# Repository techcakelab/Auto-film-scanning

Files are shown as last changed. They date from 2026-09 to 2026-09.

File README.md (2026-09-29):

# DIY Auto 35mm Film Scanner (ESP32 Autocarrier)


An open-source ESP32-based automatic film transport system for digitizing 35mm film using a digital camera. This project provides precise, high-speed frame-by-frame advancement with a custom **Hand Control Panel**.

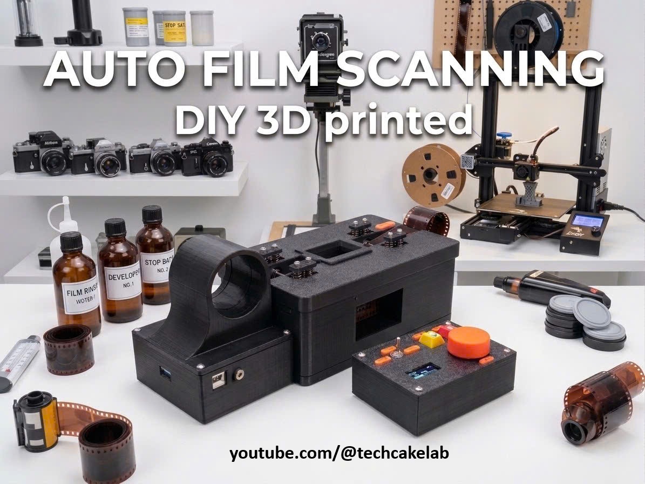
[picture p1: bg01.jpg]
Overall

---
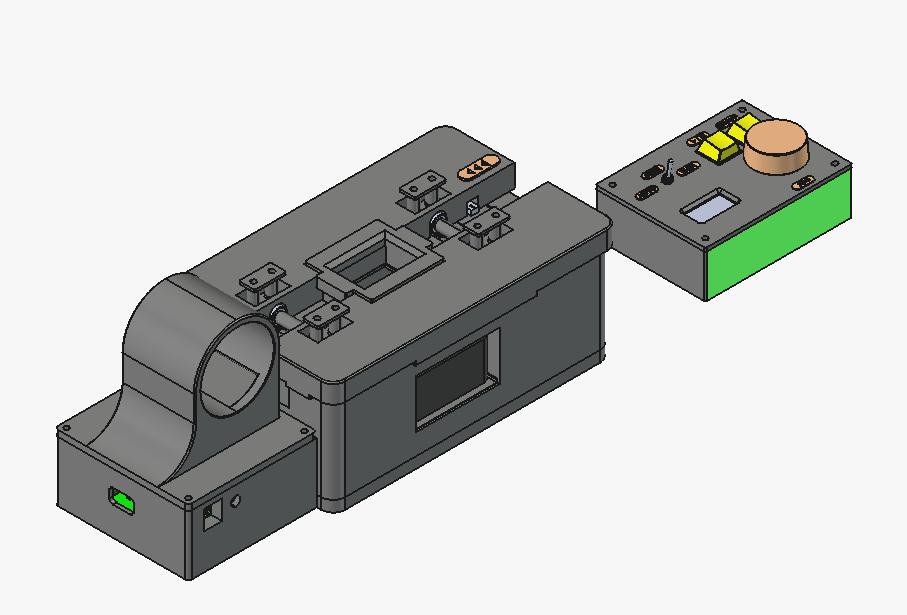
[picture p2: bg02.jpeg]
WithHandHeld

---
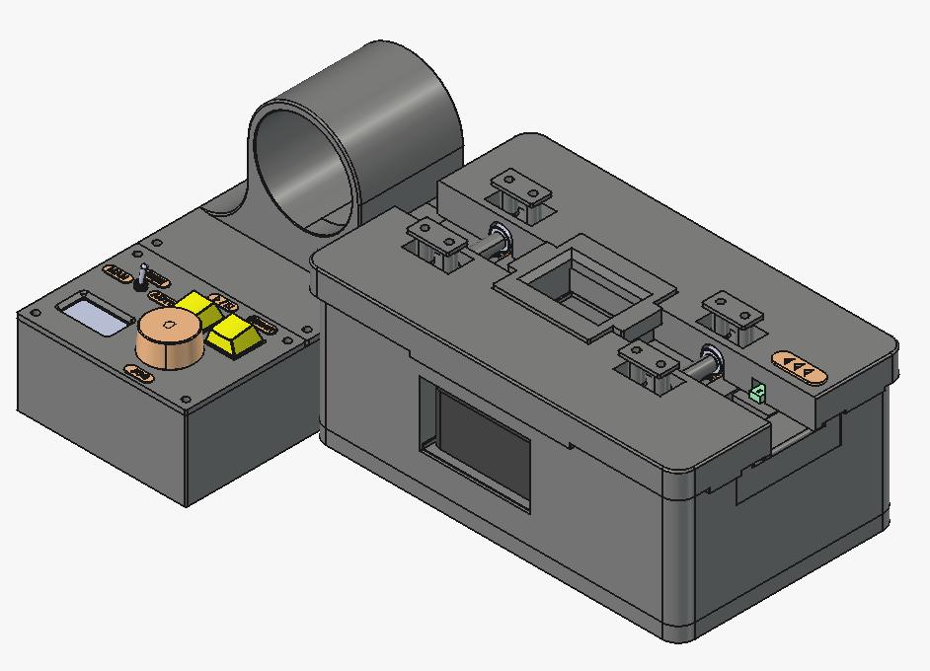
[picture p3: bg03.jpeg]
WithoutHandHeld

---

## ✨ Features

- **3 Operation Modes**: AUTO / SEMI / MANUAL
- **Sprocket-hole counting** via U-shaped optical sensor for precise frame alignment
- **Camera shutter trigger** via PC817 optocoupler module (supports 2.5mm / 3.5mm jack)
- **Hand Control Panel** via PCF8574T I2C expander (only 4 wires needed)
- **OLED display** (128x64) for real-time status
- **Web-based hardware test tools** (no app required — just connect to WiFi)
- **Serial Monitor commands** for quick debugging

---

## 🗂️ Project Structure

```
esp32_135_autocarrier/
├── esp32_135_autocarrier.ino   # Main firmware
├── config.h                    # All GPIO pin definitions & parameters
├── README.md                   # This file
├── circuit_diagram.jpg         # Full wiring block diagram
├── platformio.ini              # PlatformIO config (for VS Code users)
├── web_test_motor/             # Web UI tool: test stepper motor
├── web_test_sensor/            # Web UI tool: test optical sensor & shutter
└── web_test_servo_step/        # Web UI tool: test servo + stepper
```

---

## 🔌 Hardware List

| Component | Model | Purpose |
|---|---|---|
| Microcontroller | ESP32 Dev Module | Main controller |
| Stepper Motor Driver | TMC2209 | Drives film transport motor |
| Stepper Motor | NEMA 42 | Film transport mechanism |
| Optical Sensor | U-shaped photo interrupter | Counts sprocket holes |
| Shutter Trigger | PC817 Optocoupler module | Triggers camera shutter |
| I2C Expander | PCF8574T | Hand Control Panel interface |
| Display | 128x64 OLED (SSD1306/SH1106) | Status display |
| Power Supply | 12V DC Adapter | Main power input |
| Voltage Regulator | Mini560 DC-DC Buck (5V/5A) | 5V rail for ESP32 & logic |

---

## ⚡ Wiring (GPIO Pin Assignment)

### ESP32 → Peripherals

| ESP32 Pin | Device | Device Pin | Function |
|---|---|---|---|
| GPIO18 | TMC2209 | STEP | Step pulse |
| GPIO19 | TMC2209 | DIR | Motor direction |
| GPIO23 | TMC2209 | EN | Enable/disable motor (Active LOW) |
| GPIO25 | PC817 Module | IN+ | Camera shutter trigger |
| GPIO32 | U-shaped sensor | OUT | Sprocket hole counter (input) |
| GPIO21 | OLED + PCF8574T | SDA | I2C data |
| GPIO22 | OLED + PCF8574T | SCL | I2C clock |
| GPIO34 | PCF8574T | INT | Interrupt from Hand Control Panel |

### PCF8574T (I2C: 0x24) → Hand Control Panel

| PCF8574T Pin | Component | Function |
|---|---|---|
| P0 | KY-040 Rotary Encoder | CLK (JOG position) |
| P1 | KY-040 Rotary Encoder | DT (JOG position) |
| P2 | MTS-103 Toggle Switch | AUTO mode pin |
| P3 | MTS-103 Toggle Switch | MANUAL mode pin |
| P4 | Shutter Button | Trigger camera shutter |
| P5 | Start/Stop Button | Start / pause scanning |
| P6 | — | NC (unused) |
| P7 | — | NC (unused) |

> **Note:** MTS-103 center pin → GND. When neither P2 nor P3 is active = **SEMI** mode.
---
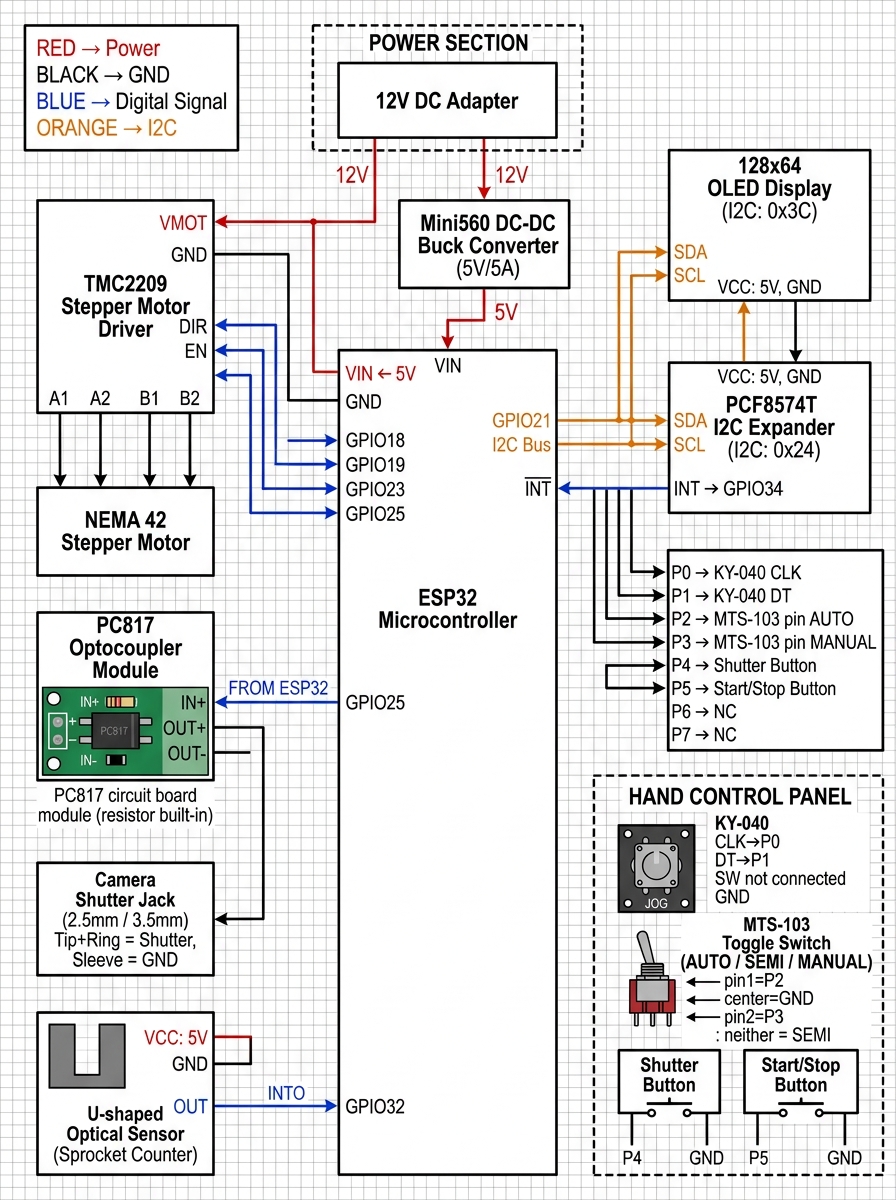
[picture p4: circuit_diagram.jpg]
Circuit Diagram

---

## 🎮 Operation Modes

### AUTO — Full Roll Scan
Press the **Start/Stop button** → System auto-triggers the camera, counts exactly **8 sprocket holes** to advance one full frame (36x24mm), then repeats until end of roll.

### SEMI — Frame-by-Frame (Safest)
Ideal for slide film (E-6) or irregularly spaced frames. Align the first frame manually → press **Shutter button** → camera fires → film advances exactly 1 frame (8 holes) → waits for next press.

### MANUAL — Hand Wheel Control
- **Turn JOG encoder clockwise** → motor advances film forward step by step.
- **Turn JOG encoder counter-clockwise** → motor rewinds film.
- **Press Shutter button** → triggers camera at the current frame.

#### 🎛️ Adjusting Motor Speed in MANUAL Mode
- **Hold the Start button for ≥ 2 seconds** → enters **Speed Adjust Mode** (OLED shows `MANUAL (SPD ADJ)`).
- While in Speed Adjust Mode, **turn the JOG encoder** to change motor speed:
  - Rotate **clockwise (CW)** → decreases step delay → **faster**.
  - Rotate **counter-clockwise (CCW)** → increases step delay → **slower**.
  - Each encoder click changes speed by **50 µs**; range: **100 µs – 3000 µs**.
- **Press Start once** → exits Speed Adjust Mode, returns to normal JOG.

> **Note:** The speed value is stored in `speedDelay` (µs between step pulses).  
> Changes take effect immediately on the next JOG move and persist for AUTO/SEMI runs within the same session.

---

## 🔋 Power Supply

```
12V DC Adapter
    |
    |--► VMOT (TMC2209) — Motor power rail (12V)
    |
    └--► Mini560 DC-DC Buck Converter
              |
              └--► 5V --► ESP32 VIN + all 5V logic
```

---

## 📷 Camera Shutter Connection (PC817 Module)

The PC817 optocoupler **module** (resistor built-in) provides galvanic isolation between ESP32 and camera:

```
ESP32 GPIO25 --► IN+  [PC817 Module]  OUT+ --► Camera Jack Tip + Ring (Shutter / Focus)
ESP32 GND    --► IN-                  OUT- --► Camera Jack Sleeve (GND)
```

Supports standard **2.5mm** or **3.5mm** camera remote shutter jacks.

---

## 🖥️ Serial Monitor Commands (Baud: 115200)

Connect via USB and send commands:

| Command | Action |
|---|---|
| `start` | Start auto scanning |
| `stop` | Emergency stop |
| `mode auto` | Switch to AUTO mode |
| `mode semi` | Switch to SEMI mode |
| `mode manual` | Switch to MANUAL mode |
| `full` | Set Full-Frame (8 holes per frame) |
| `half` | Set Half-Frame (4 holes per frame) |
| `reset` | Reset frame counter to 0 |

---

## 🌐 Web-Based Hardware Test Tools

Each sub-folder contains a standalone test sketch. Flash it separately to test hardware without the main firmware.

### `web_test_motor/`
- **WiFi AP:** `ESP32_Autocarrier_Test` | Password: `12345678`
- **URL:** http://192.168.4.1
- Test stepper motor: step jogging, continuous run, speed (us delay), enable/disable driver.

### `web_test_sensor/`
- Test U-shaped optical sensor (live sprocket count).
- Test camera shutter trigger via PC817 optocoupler.

### `web_test_servo_step/`
- Servo angle slider (0-180 degrees) with Auto Sweep mode.
- Combined stepper + servo test.

---

## 🛠️ Flashing the Firmware

### Arduino IDE
1. Open `esp32_135_autocarrier.ino` in Arduino IDE.
2. Install libraries via **Library Manager**:
   - `Adafruit SH110X`
   - `Adafruit GFX Library`
3. Select board: **ESP32 Dev Module**.
4. Select the correct COM port → click **Upload**.

### PlatformIO (VS Code)
```bash
pio run --target upload
```

---

## ⚙️ Key Parameters (`config.h`)

| Define | Default | Description |
|---|---|---|
| `HOLES_FULL_FRAME` | `8` | Sprocket holes per full frame (36x24mm) |
| `HOLES_HALF_FRAME` | `4` | Sprocket holes per half frame (18x24mm) |
| `DEFAULT_STEP_DELAY_US` | `570` | Motor speed (us between step pulses) |
| `JOG_STEPS_PER_CLICK` | `32` | Motor steps per JOG encoder click |
| `SENSOR_DEBOUNCE_US` | `15000` | Optical sensor debounce time (us) |
| `SHUTTER_PULSE_MS` | `300` | Shutter trigger pulse duration (ms) |
| `POST_SHUTTER_DELAY_MS` | `400` | Wait after shutter before advancing (ms) |
| `SETTLE_DELAY_MS` | `80` | Vibration settle time before shutter (ms) |
| `FILM_TIMEOUT_MS` | `4500` | Film advance timeout protection (ms) |

---

## 📄 License

This project is released as open-source. Feel free to use, modify, and share.

---

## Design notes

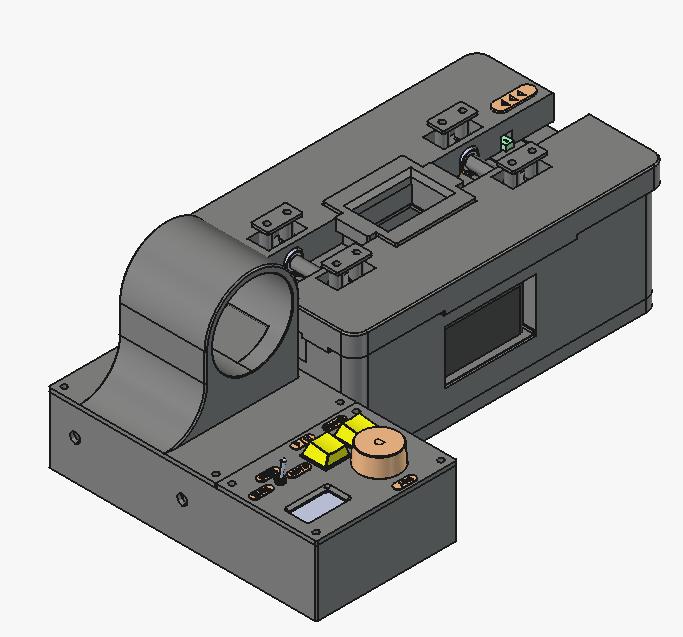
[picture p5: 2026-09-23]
images/overall - wo handheld 3.jpeg

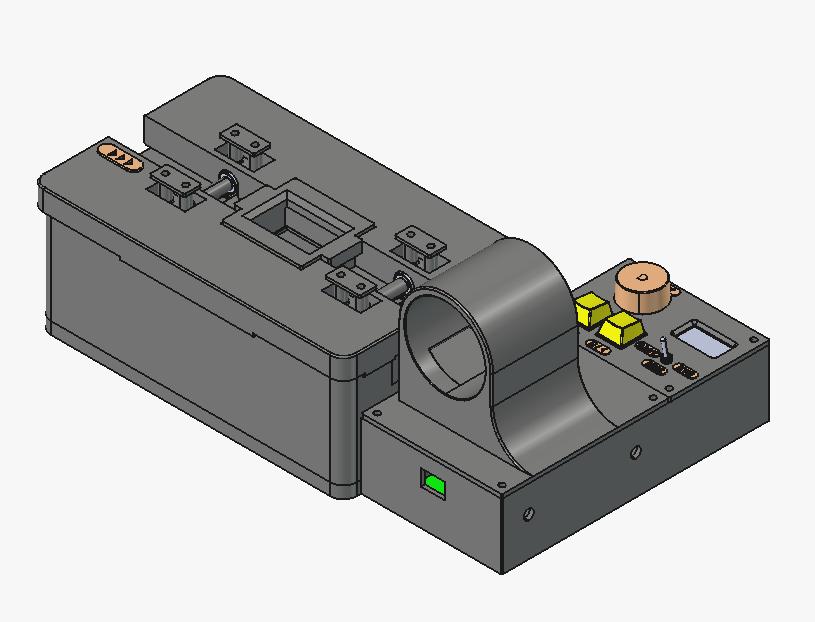
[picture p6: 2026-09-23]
images/overall - wo handheld 4.jpeg

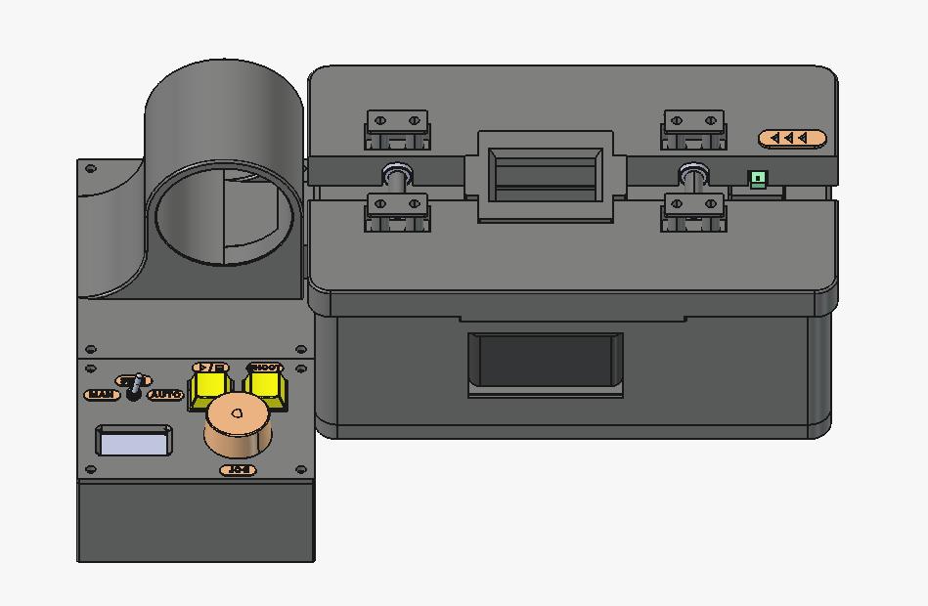
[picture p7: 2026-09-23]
images/overall - wo handheld 2.jpeg

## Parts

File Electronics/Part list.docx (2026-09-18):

Part list:

1. ESP32 board: 1 pc
2. ESP32 extension board: 1 pc
3. 12V adaptor: 1 pc
4. Magnetic dia6 – thickness 3: 36 pcs
5. ZoeRax Cat6 RJ45 Jack: 2 pcs
6. DC-DC buck mini560 5V 5A: 1 pc
7. Encoder KY-40: 1pc
8. Cherry Key: 2 pcs
9. Nema17 step motor: 1 pc
10. 686 Bearing: 12 pcs
11. O-ring d8-2mm: 4pcs
12. Oled 1.3inch: 1 pc
13. Spring ID 10mm – L20mm: 8pcs
14. PCF8574 module: 1 pc
15. Ulanzi VL49 Led: 1 pc
16. EE-SX672-WR sensor: 1 pc
17. Pulley GT2-20T-d6: 3 pcs
18. Pulley GT2-20T-d5: 1 pcs
19. Timing belt GT2 – L110: 1 pc
20. Timing belt GT2 – L300: 1 pc
21. Camera wire remote: 1 pc
22. PC817 module: 1 pc
23. TMC2209 driver: 1 pc

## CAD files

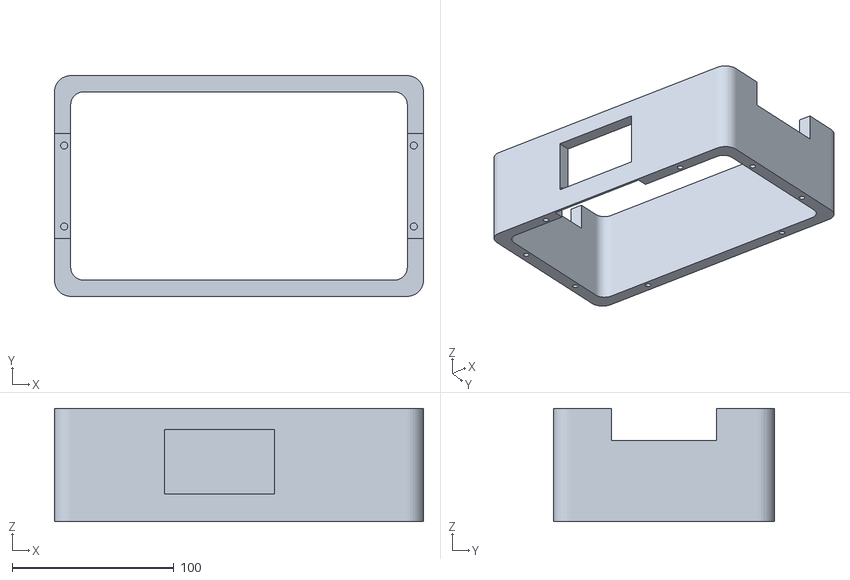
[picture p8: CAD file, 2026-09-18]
3D_models/Main cover - qty 1.STL
228.0 x 136.4 x 70.0

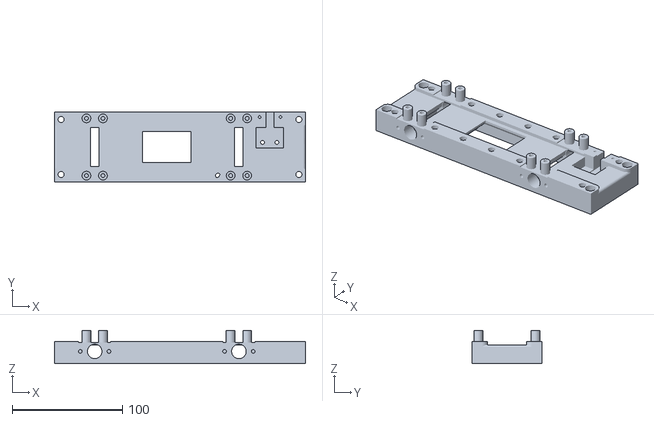
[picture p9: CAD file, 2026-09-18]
3D_models/Main guide - qty 1.STL
228.0 x 64.0 x 30.0

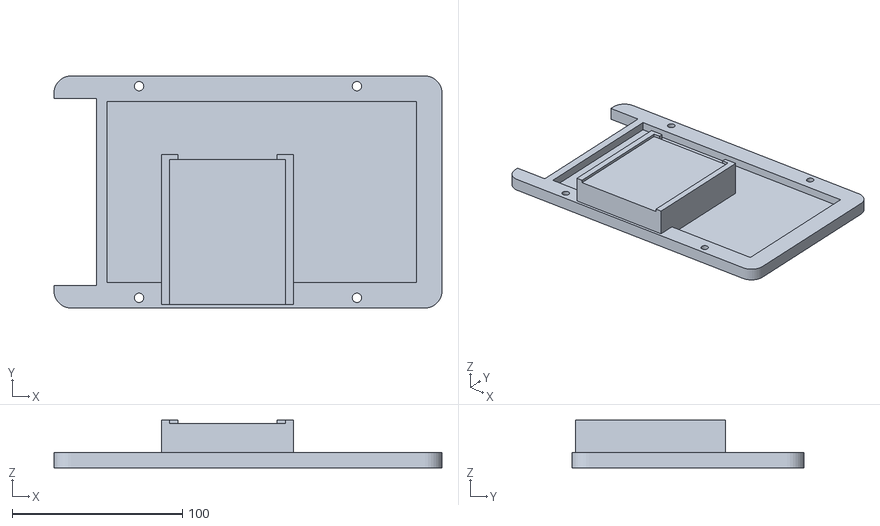
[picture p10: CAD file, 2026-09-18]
3D_models/Main base plate - qty 1.STL
228.0 x 136.4 x 28.0

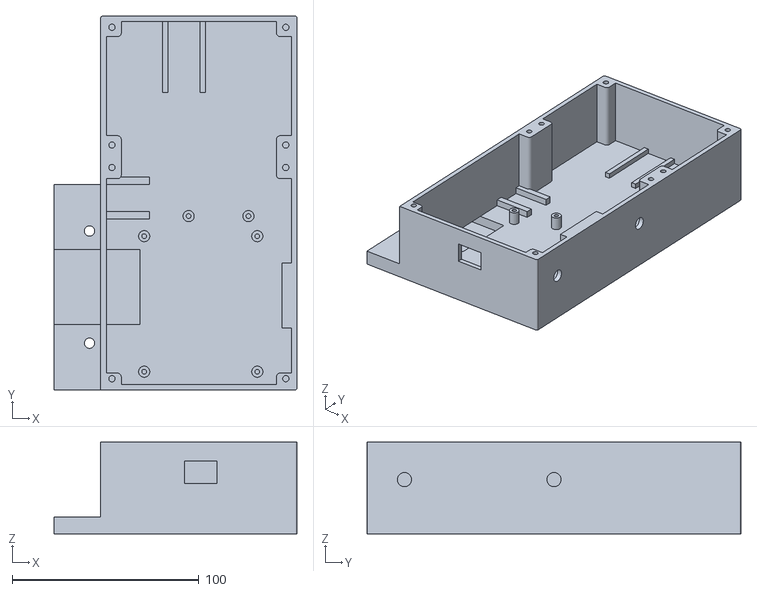
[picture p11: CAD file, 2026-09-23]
3D_models/E Box 2 - qty 1.STL
130.0 x 200.0 x 49.0

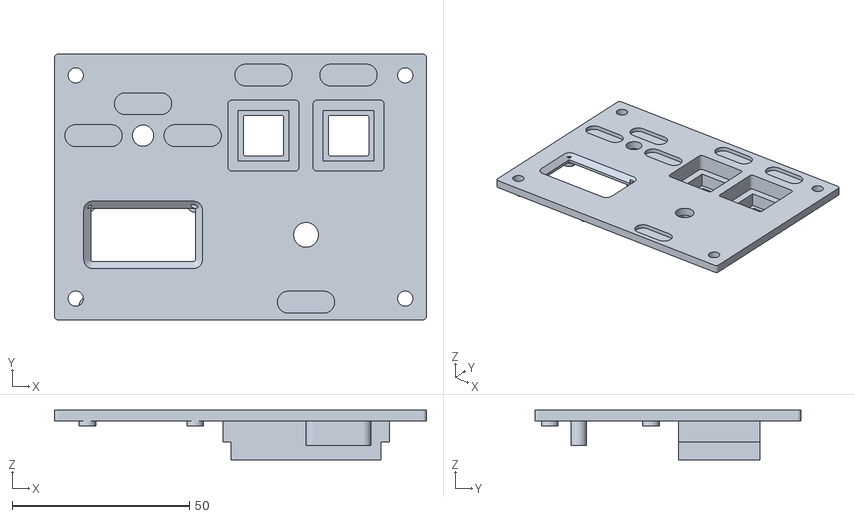
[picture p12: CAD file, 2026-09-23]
3D_models/Panel face 2 - qty 1.STL
105.0 x 75.0 x 14.0

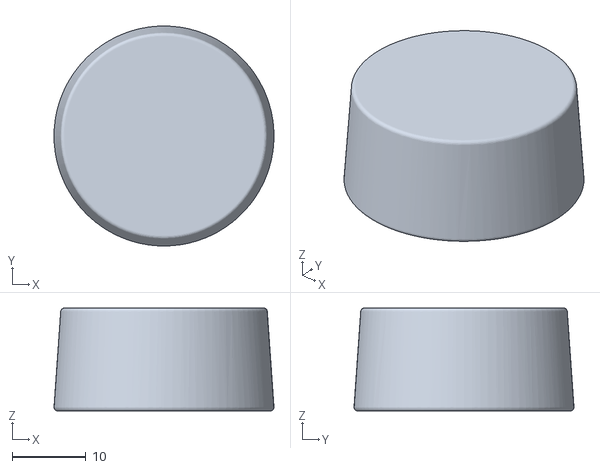
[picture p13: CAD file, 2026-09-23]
3D_models/Wheel 2 - qty 1.STL
29.9 x 29.9 x 14.0

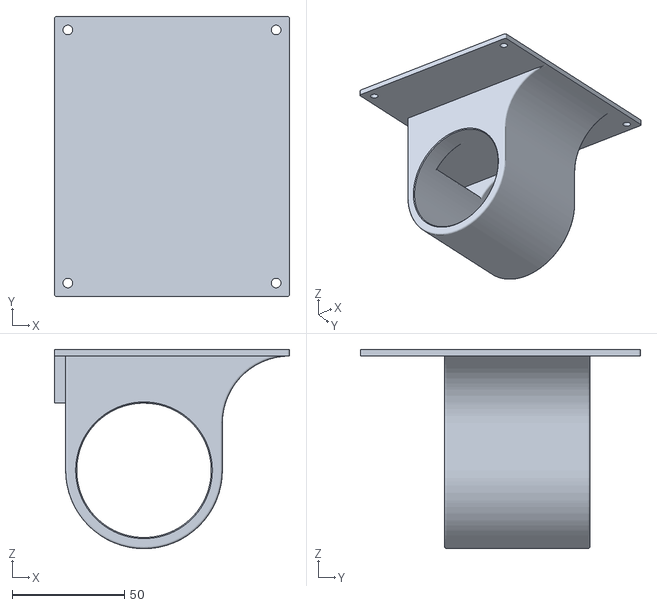
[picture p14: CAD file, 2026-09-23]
3D_models/Roll guide 2 - qty 1.STL
105.0 x 125.0 x 89.0

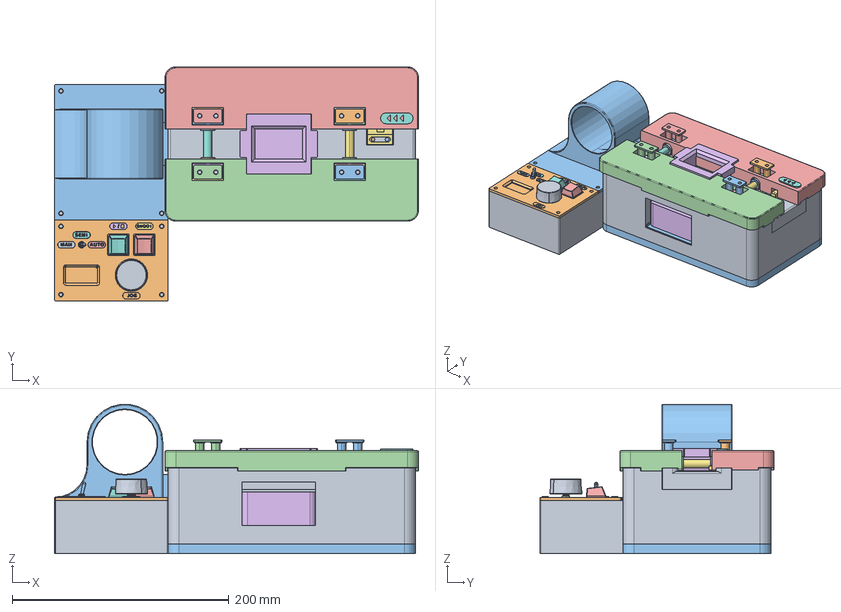
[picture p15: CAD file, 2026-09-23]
3D_models/3DFreecad - wo handheld.FCStd
336.0 x 216.2 x 137.7 mm
Main guide - qty 1
Driven shaft - qty 1
Guide plate - qty 4
Guide plate - qty 001
Guide plate - qty 002
Guide plate - qty 003
Idle shaft - qty 2
Idle shaft - qty 001
Main cover - qty 1
Spring guide - qty 4
Spring guide - qty 001
Spring guide - qty 002
Spring guide - qty 003
Idle shaft 2 - qty 1
Bearing flange - qty 4
Bearing flange - qty 001
Bearing flange - qty 002
Bearing flange - qty 003
Main base plate - qty 1
Side guide 1 - qty 1
Side guide 2 - qty 1
Mask - qty 1
Sensor slot - qty 1
Text DIRECTION
Bearing 686ZZ
Bearing 686ZZ001
Bearing 686ZZ002
Bearing 686ZZ003
Oring d8-2
Oring d8-001
Oring d8-002
Oring d8-003
Pulley 20GT2060-A-H6
Pulley 20GT2060-A-H001
Pulley 20GT2060-A-H002
Pulley 20GT2060-A-H003
NEMA 17
Ulanzi VL49
Bearing 686ZZ004
Bearing 686ZZ005
Bearing 686ZZ006
Bearing 686ZZ007
Bearing 686ZZ008
Bearing 686ZZ009
Bearing 686ZZ010
Bearing 686ZZ011
U sensor - EE-SX672
Motor flange
E Box 2 - qty 1
Panel face 2 - qty 1
Roll guide 2 - qty 1
ESP32_expansion_terminal_board
TMC2209
Conversor DC-DC Step Down Mini 560 PRO
PC817-2CH
Key-cap
Wheel - qty 1
OLED13 IIC
MTS-1xx-A2-blue
KY-040 Rotary Encoder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

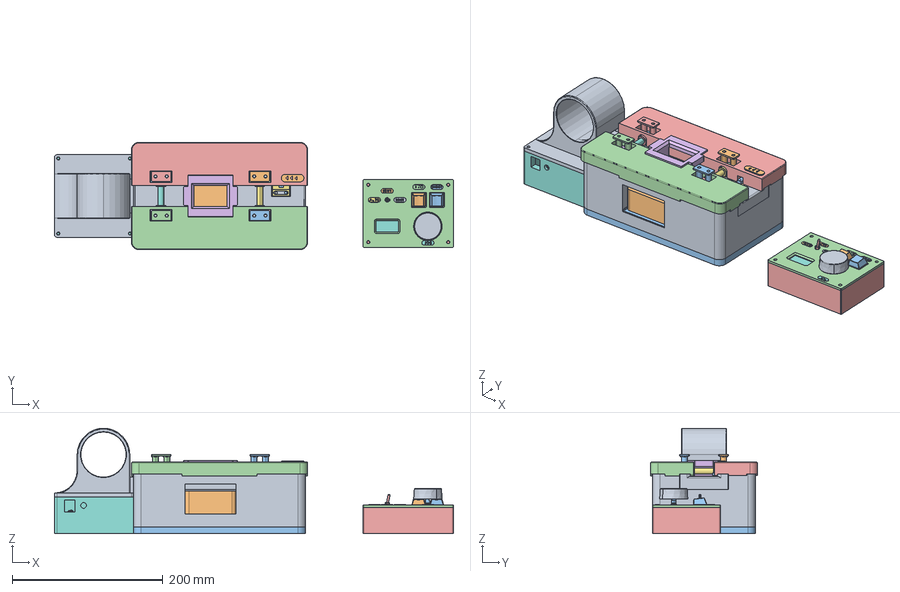
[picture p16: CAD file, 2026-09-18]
3D_models/3DFreecad - with handheld.FCStd
529.5 x 142.4 x 140.0 mm
Main guide - qty 1
Driven shaft - qty 1
Guide plate - qty 4
Guide plate - qty 001
Guide plate - qty 002
Guide plate - qty 003
Idle shaft - qty 2
Idle shaft - qty 001
Main cover - qty 1
Spring guide - qty 4
Spring guide - qty 001
Spring guide - qty 002
Spring guide - qty 003
Idle shaft 2 - qty 1
Bearing flange - qty 4
Bearing flange - qty 001
Bearing flange - qty 002
Bearing flange - qty 003
Main base plate - qty 1
Side guide 1 - qty 1
Side guide 2 - qty 1
Mask - qty 1
Sensor slot - qty 1
E Box - qty 1
Roll guide - qty 1
Text DIRECTION
KY-040 Rotary Encoder
Panel face - qty 1
MTS-1xx-A2-blue
Button
Button001
OLED13 IIC
Wheel - qty 1
Key-cap
Key-cap001
PCF8574
Panel bottom - qty 1
RJ45
Text AUTO
Text JOG
Text MANUAL
Text SEMI
Text SHOOT
Text START
Bearing 686ZZ
Bearing 686ZZ001
Bearing 686ZZ002
Bearing 686ZZ003
Oring d8-2
Oring d8-001
Oring d8-002
Oring d8-003
Pulley 20GT2060-A-H6
Pulley 20GT2060-A-H001
Pulley 20GT2060-A-H002
Pulley 20GT2060-A-H003
NEMA 17
Ulanzi VL49
Bearing 686ZZ004
Bearing 686ZZ005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

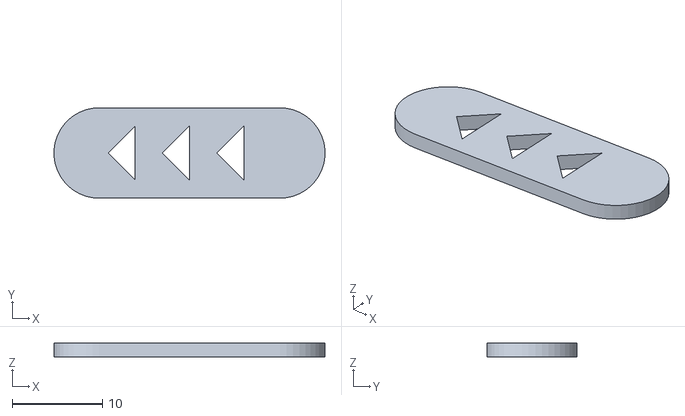
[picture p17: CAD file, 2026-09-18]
3D_models/Text DIRECTION.STL
30.0 x 10.0 x 1.50

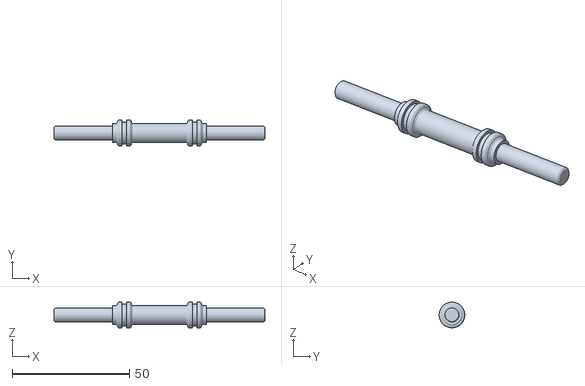
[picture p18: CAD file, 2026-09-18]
3D_models/Driven shaft - qty 1.STL
90.0 x 11.0 x 11.0

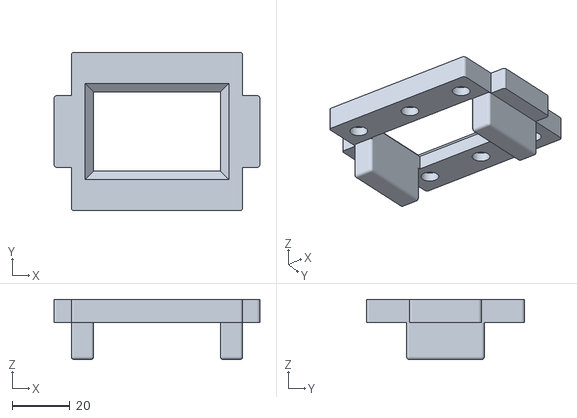
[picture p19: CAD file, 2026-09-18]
3D_models/Mask - qty 1.STL
71.6 x 55.0 x 20.9

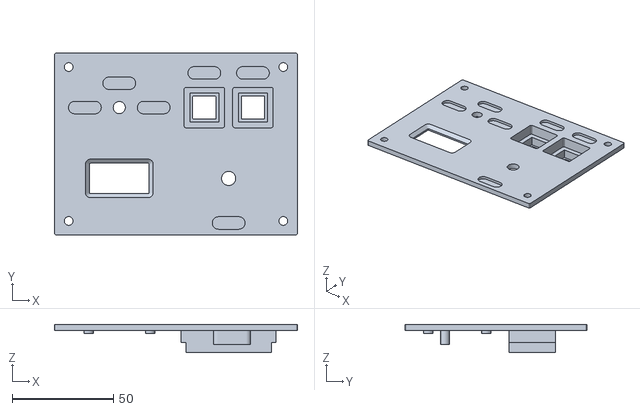
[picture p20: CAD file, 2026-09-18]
3D_models/Panel face - qty 1.STL
120.0 x 90.0 x 14.0

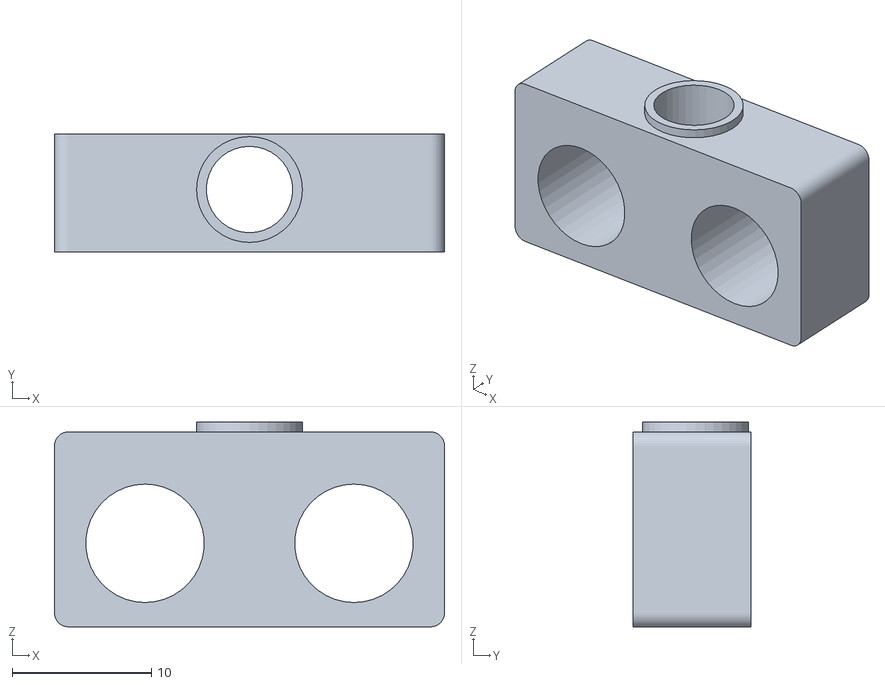
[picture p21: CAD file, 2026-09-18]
3D_models/Guide plate - qty 4.STL
28.0 x 8.50 x 14.7

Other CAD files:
3D_models/Motor flange.STL
3D_models/Text AUTO.STL
3D_models/Text JOG.STL
3D_models/Text START.STL
3D_models/Bearing flange - qty 4.STL
3D_models/E Box - qty 1.STL
3D_models/Idle shaft - qty 2.STL
3D_models/Idle shaft 2 - qty 1.STL
3D_models/Panel bottom - qty 1.STL
3D_models/Roll guide - qty 1.STL
3D_models/Sensor slot - qty 1.STL
3D_models/Side guide 1 - qty 1.STL
3D_models/Side guide 2 - qty 1.STL
3D_models/Spring guide - qty 4.STL
3D_models/Text MANUAL.STL
3D_models/Text SEMI.STL
3D_models/Text SHOOT.STL
3D_models/Wheel - qty 1.STL

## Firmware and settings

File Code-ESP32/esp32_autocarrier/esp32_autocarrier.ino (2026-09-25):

#include <Arduino.h>
#include <Wire.h>
#include <Adafruit_GFX.h>
#include <Adafruit_SH110X.h>
#include <AccelStepper.h>
#include "config.h"

// --- OLED DISPLAY INIT ---
Adafruit_SH1106G display(SCREEN_WIDTH, SCREEN_HEIGHT, &Wire, -1);
bool hasOLED = false;

// --- STEPPER MOTOR INIT ---
AccelStepper stepper(AccelStepper::DRIVER, PIN_MOTOR_STEP, PIN_MOTOR_DIR);

// --- OPERATION MODES ---
enum OperationMode {
  MODE_MANUAL, // Turn JOG encoder to move film; press Shutter button to capture
  MODE_SEMI,   // Press Start -> advance 8 holes -> capture -> wait for next Start press
  MODE_AUTO    // Press Start -> (advance 8 holes -> capture -> repeat) continuously
};
OperationMode currentOpMode = MODE_MANUAL;

// --- SYSTEM STATE (STATE MACHINE) ---
enum SystemState {
  STATE_IDLE,
  STATE_RUNNING,       // Advancing film, counting sprocket holes
  STATE_SETTLING,      // Waiting for mechanical vibration to settle
  STATE_TRIGGERING,    // Triggering camera shutter
  STATE_WAIT_EXPOSURE, // Waiting for exposure and file save
  STATE_JOGGING        // Manual JOG encoder movement
};
SystemState currentState = STATE_IDLE;

// --- OPERATING PARAMETERS ---
int speedDelay = DEFAULT_STEP_DELAY_US; // Step delay in microseconds
int holeCount = 0;
int currentFrame = 0;
unsigned long stateTimer = 0;

// --- SENSOR & BUTTON VARIABLES ---
int lastUSensorState = HIGH;
unsigned long lastDebounceTime = 0;

bool lastBtnShutterState = true;
bool lastBtnStartState = true;
unsigned long startBtnPressTime = 0;
bool isJogSpeedAdjustMode = false;

// --- PCF8574 VARIABLES ---
volatile bool flag_pcf_changed = false;
uint8_t lastPcfState = 0xFF; // Initially all HIGH
uint8_t lastJogEncodedState = 0;
uint8_t lastSpdEncodedState = 0;

//
// ================================================================
//
void IRAM_ATTR isr_pcf() {
  flag_pcf_changed = true;
}


//
// 2. GIAO DIỆN WEB (REMOVED)
//

void updateDisplay() {
  if (!hasOLED) return;
  display.clearDisplay();
  display.setTextSize(1);
  display.setTextColor(SH110X_WHITE);
  
  // Current mode
  display.setCursor(0, 0);
  display.print(F("MODE: "));
  if (currentOpMode == MODE_AUTO) display.print(F("AUTO SCAN"));
  else if (currentOpMode == MODE_SEMI) display.print(F("SEMI-AUTO"));
  else {
    if (isJogSpeedAdjustMode) display.print(F("MANUAL (SPD ADJ)"));
    else display.print(F("MANUAL"));
  }

  // Parameters
  display.setCursor(0, 15);
  display.printf("Frm: %02d | H: %d/8", currentFrame, holeCount);
  
  display.setCursor(0, 30);
  display.printf("Spd: %dus", speedDelay);

  // Operating state
  display.setCursor(0, 45);
  switch (currentState) {
    case STATE_IDLE: display.print(F("READY / IDLE")); break;
    case STATE_RUNNING: display.print(F(">> ADVANCING FILM >>")); break;
    case STATE_SETTLING: display.print(F("Settling...")); break;
    case STATE_TRIGGERING: display.print(F("--> CAPTURING <--")); break;
    case STATE_WAIT_EXPOSURE: display.print(F("Saving file...")); break;
    case STATE_JOGGING: display.print(F("Jogging...")); break;
  }
  display.display();
}

void processStartCommand() {
  if (currentState == STATE_IDLE) {
    if (currentOpMode == MODE_AUTO || currentOpMode == MODE_SEMI) {
      currentState = STATE_TRIGGERING;
      stateTimer = millis();
      Serial.println(">>> START: Capture first, then advance <<<");
      updateDisplay();
    }
  }
}

void processStopCommand() {
  currentState = STATE_IDLE;
  stepper.stop();
  stepper.disableOutputs();
  digitalWrite(PIN_SHUTTER_OPTO, LOW); // Ensure shutter is released
  Serial.println(">>> STOPPED <<<");
  updateDisplay();
}



//
// 3. SETUP
//
void setup() {
  Serial.begin(115200);

  // Configure motor GPIO pins
  pinMode(PIN_MOTOR_STEP, OUTPUT);
  pinMode(PIN_MOTOR_DIR, OUTPUT);
  pinMode(PIN_MOTOR_EN, OUTPUT);

  // Configure AccelStepper
  stepper.setEnablePin(PIN_MOTOR_EN);
  stepper.setPinsInverted(true, false, true); // Invert DIR; EN is active LOW
  stepper.setMinPulseWidth(20);
  stepper.setAcceleration(800.0);
  stepper.setMaxSpeed((1000000.0 / DEFAULT_STEP_DELAY_US) * 0.6);
  stepper.disableOutputs();

  // Configure shutter optocoupler output
  pinMode(PIN_SHUTTER_OPTO, OUTPUT);
  digitalWrite(PIN_SHUTTER_OPTO, LOW);

  // Configure U-shaped optical sensor
  pinMode(PIN_U_SENSOR, INPUT_PULLUP);

  // Start I2C bus (shared by OLED and PCF8574T)
  Wire.begin(PIN_OLED_SDA, PIN_OLED_SCL);

  // --- SCAN I2C BUS ---
  Serial.println("\n--- SCANNING I2C BUS FOR DEVICES ---");
  int foundCount = 0;
  for (byte i = 1; i < 127; i++) {
    Wire.beginTransmission(i);
    if (Wire.endTransmission() == 0) {
      Serial.printf("-> Device found at: 0x%02X\n", i);
      foundCount++;
    }
  }
  if (foundCount == 0) {
    Serial.println("-> NO I2C DEVICES FOUND ON BUS!");
  }
  Serial.println("--------------------------------------\n");

  // --- CHECK PCF8574T ---
  Wire.beginTransmission(I2C_ADDRESS_PCF);
  byte errorPCF = Wire.endTransmission();
  if (errorPCF == 0) {
    Serial.printf("[OK] PCF8574T found at address: 0x%02X\n", I2C_ADDRESS_PCF);
    // Configure PCF8574T interrupt
    pinMode(PIN_PCF_INT, INPUT_PULLUP);
    attachInterrupt(digitalPinToInterrupt(PIN_PCF_INT), isr_pcf, FALLING);
    Wire.beginTransmission(I2C_ADDRESS_PCF);
    Wire.write(0xFF); // Set all P0-P7 pins as input (pull-up)
    Wire.endTransmission();
  } else {
    Serial.println("[ERROR] PCF8574T not found. Check SDA/SCL wiring!");
  }

  // --- CHECK OLED ---
  Wire.beginTransmission(OLED_I2C_ADDRESS);
  byte errorOLED = Wire.endTransmission();
  if (errorOLED == 0) {
    if (display.begin(OLED_I2C_ADDRESS, true)) {
      Serial.printf("[OK] OLED display found at address: 0x%02X\n", OLED_I2C_ADDRESS);
      hasOLED = true;
      display.clearDisplay();
      display.setTextSize(1);
      display.setTextColor(SH110X_WHITE);
      display.setCursor(10, 20);
      display.println(F("Have a nice day !!!"));
      display.display();
      delay(1500);
    }
  } else {
    Serial.printf("[ERROR] OLED not found at address: 0x%02X\n", OLED_I2C_ADDRESS);
  }

  updateDisplay();
}

//
// 4. MAIN LOOP
//
void loop() {
  unsigned long currentMicros = micros();
  unsigned long currentMillis = millis();

  // ----------------------------------------------------
  // READ I2C PCF8574T (BUTTONS & ENCODER)
  // ----------------------------------------------------
  if (flag_pcf_changed) {
    flag_pcf_changed = false;
    
    Wire.requestFrom(I2C_ADDRESS_PCF, 1);
    if (Wire.available()) {
      uint8_t pcfState = Wire.read();

      // 1. Decode mode toggle switch (MTS-103)
      bool isAutoMode = !((pcfState >> PCF_PIN_MODE_AUTO) & 1);
      bool isManualMode = !((pcfState >> PCF_PIN_MODE_MANUAL) & 1);
      
      OperationMode newMode;
      if (isAutoMode) newMode = MODE_AUTO;
      else if (isManualMode) newMode = MODE_MANUAL;
      else newMode = MODE_SEMI;

      if (newMode != currentOpMode && currentState == STATE_IDLE) {
        currentOpMode = newMode;
        updateDisplay();
      }

      // 2. Decode Shutter button (P4)
      bool btnShutter = (pcfState >> PCF_PIN_BTN_SHUTTER) & 1;
      if (lastBtnShutterState == true && btnShutter == false) { // Falling edge (HIGH -> LOW)
        if (currentState == STATE_IDLE && currentOpMode == MODE_MANUAL) {
          currentState = STATE_TRIGGERING;
          stateTimer = currentMillis;
          updateDisplay();
        }
      }
      lastBtnShutterState = btnShutter;

      // 3. Decode Start/Stop button (P5)
      bool btnStart = (pcfState >> PCF_PIN_BTN_START) & 1;
      if (lastBtnStartState == true && btnStart == false) { // Falling edge (HIGH -> LOW)
        startBtnPressTime = currentMillis;
        if (currentOpMode == MODE_MANUAL) {
          if (isJogSpeedAdjustMode) {
            isJogSpeedAdjustMode = false;
            updateDisplay();
          }
        } else {
          if (currentState == STATE_IDLE) {
            processStartCommand();
          } else if (currentState == STATE_RUNNING || currentState == STATE_JOGGING) {
            processStopCommand();
          }
        }
      }
      lastBtnStartState = btnStart;

      // 4. Decode JOG encoder (P0, P1)
      uint8_t jogMSB = (pcfState >> PCF_PIN_ENC_JOG_CLK) & 1;
      uint8_t jogLSB = (pcfState >> PCF_PIN_ENC_JOG_DT) & 1;
      uint8_t jogEncoded = (jogMSB << 1) | jogLSB;
      uint8_t jogSum = (lastJogEncodedState << 2) | jogEncoded;

      int encoderJogDelta = 0;
      if (jogSum == 0b1101 || jogSum == 0b0100 || jogSum == 0b0010 || jogSum == 0b1011) encoderJogDelta = 1;
      if (jogSum == 0b1110 || jogSum == 0b0111 || jogSum == 0b0001 || jogSum == 0b1000) encoderJogDelta = -1;
      lastJogEncodedState = jogEncoded;

      if (encoderJogDelta != 0 && currentState == STATE_IDLE && currentOpMode == MODE_MANUAL) {
        if (isJogSpeedAdjustMode) {
          speedDelay -= encoderJogDelta * 50;
          if (speedDelay < 100) speedDelay = 100;
          if (speedDelay > 3000) speedDelay = 3000;
          stepper.setMaxSpeed((1000000.0 / speedDelay) * 0.6);
          updateDisplay();
        } else {
          long steps = abs(encoderJogDelta) * JOG_STEPS_PER_CLICK;
          if (encoderJogDelta < 0) steps = -steps;
          stepper.enableOutputs();
          stepper.setAcceleration(800.0);
          stepper.setMaxSpeed((1000000.0 / speedDelay) * 2.4); // Tốc độ JOG x2 so với trước
          stepper.move(steps);
          currentState = STATE_JOGGING;
          updateDisplay();
        }
      }

      lastPcfState = pcfState;
    }
  }

  // Hold Start button 2 seconds in MANUAL mode to enter speed-adjust mode
  if (!lastBtnStartState && currentOpMode == MODE_MANUAL && !isJogSpeedAdjustMode) {
    if (currentMillis - startBtnPressTime >= 2000) {
      isJogSpeedAdjustMode = true;
      updateDisplay();
    }
  }

  // ----------------------------------------------------
  // MOTOR CONTROL
  // ----------------------------------------------------
  stepper.run();

  // ----------------------------------------------------
  // STATE MACHINE
  // ----------------------------------------------------
  switch (currentState) {
    case STATE_IDLE:
      // Nothing to do, waiting for command
      break;
      
    case STATE_JOGGING:
      if (stepper.distanceToGo() == 0) {
        // Do NOT disable motor here — keep magnetic brake engaged
        currentState = STATE_IDLE;
        updateDisplay();
      }
      break;

    case STATE_RUNNING:
      // Poll U-shaped optical sensor for sprocket holes
      {
        int sensorVal = digitalRead(PIN_U_SENSOR);
        if (sensorVal != lastUSensorState) {
          if (currentMicros - lastDebounceTime > SENSOR_DEBOUNCE_US) {
            lastUSensorState = sensorVal;
            lastDebounceTime = currentMicros; // Reset debounce timer
            // Falling edge (LOW) = sprocket hole detected
            if (sensorVal == LOW) {
              holeCount++;
              Serial.printf("Hole detected: %d/8\n", holeCount);
              updateDisplay();
              
              if (holeCount >= HOLES_FULL_FRAME) {
                // All 8 holes counted -> hard brake to prevent overshoot
                stepper.setAcceleration(20000.0); // Max deceleration for instant stop
                stepper.stop();
                currentState = STATE_SETTLING;
                stateTimer = currentMillis;
                Serial.println("8 holes counted. Waiting for vibration to settle...");
                updateDisplay();
              }
            }
          }
        }
      }
      break;

    case STATE_SETTLING:
      if (stepper.distanceToGo() == 0) {
        if (currentMillis - stateTimer >= SETTLE_DELAY_MS) {
          if (currentOpMode == MODE_AUTO) {
            currentState = STATE_TRIGGERING;
            stateTimer = currentMillis;
          } else {
            currentState = STATE_IDLE;
            Serial.println("SEMI cycle complete. Waiting for next Start command...");
          }
          updateDisplay();
        }
      } else {
        // Keep resetting timer until motor fully stops
        stateTimer = currentMillis;
      }
      break;

    case STATE_TRIGGERING:
      digitalWrite(PIN_SHUTTER_OPTO, HIGH); // Trigger camera shutter
      if (currentMillis - stateTimer >= SHUTTER_PULSE_MS) {
        digitalWrite(PIN_SHUTTER_OPTO, LOW);
        currentState = STATE_WAIT_EXPOSURE;
        stateTimer = currentMillis;
        currentFrame++; // Increment frame counter
        updateDisplay();
      }
      break;

    case STATE_WAIT_EXPOSURE:
      // Wait for camera to finish exposure and release shutter
      if (currentMillis - stateTimer >= POST_SHUTTER_DELAY_MS) {
        if (currentOpMode == MODE_AUTO || currentOpMode == MODE_SEMI) {
          // Advance to next frame
          holeCount = 0;
          stepper.enableOutputs();
          stepper.setAcceleration(800.0); // Restore smooth acceleration
          stepper.setMaxSpeed((1000000.0 / speedDelay) * 0.6);
          stepper.setCurrentPosition(0);
          stepper.move(1000000);
          currentState = STATE_RUNNING;
          Serial.println("Advancing to next frame...");
        } else {
          // MANUAL mode: capture only, no auto-advance
          currentState = STATE_IDLE;
        }
        updateDisplay();
      }
      break;
  }
}

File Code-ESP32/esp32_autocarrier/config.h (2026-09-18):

#ifndef CONFIG_H
#define CONFIG_H

// ================================================================
// ESP32 GPIO PIN ASSIGNMENT
// ================================================================

// 1. NEMA 42 Stepper Motor Driver (TMC2209)
#define PIN_MOTOR_STEP 18 // Step pulse pin
#define PIN_MOTOR_DIR 19  // Direction pin
#define PIN_MOTOR_EN 23   // Enable pin (Active LOW)

// 2. Camera shutter trigger via PC817 Optocoupler module
#define PIN_SHUTTER_OPTO 25 // Shutter trigger output

// 3. U-shaped optical sensor (counts film sprocket holes)
#define PIN_U_SENSOR 32

// 4. HAND CONTROL PANEL (detached) - PCF8574T I2C Expander
#define I2C_ADDRESS_PCF 0x24 // I2C address of PCF8574T
#define PIN_PCF_INT 34       // Interrupt pin from PCF8574T to ESP32

// PCF8574T bit mapping (P0 - P5)
#define PCF_PIN_ENC_JOG_CLK 0  // KY-040 Jog encoder - CLK
#define PCF_PIN_ENC_JOG_DT  1  // KY-040 Jog encoder - DT
#define PCF_PIN_MODE_AUTO   2  // MTS-103 toggle switch - AUTO pin
#define PCF_PIN_MODE_MANUAL 3  // MTS-103 toggle switch - MANUAL pin
#define PCF_PIN_BTN_SHUTTER 4  // Shutter button
#define PCF_PIN_BTN_START   5  // Start/Stop button

// 5. OLED Display SSD1306/SH1106 I2C
#define PIN_OLED_SDA 21

#define PIN_OLED_SCL 22
#define OLED_I2C_ADDRESS 0x3C
#define SCREEN_WIDTH 128
#define SCREEN_HEIGHT 64

// ================================================================
// OPERATING PARAMETERS & 35MM FILM STANDARDS
// ================================================================

// Number of sprocket holes per frame
#define HOLES_FULL_FRAME 8 // Full Frame 35mm: 36x24mm + 2mm gap = 8 holes (38mm)
#define HOLES_HALF_FRAME 4 // Half Frame 35mm: 18x24mm = 4 holes (19mm)

// Motor transport speed (microseconds delay between step pulses)
#define DEFAULT_STEP_DELAY_US 570

// Motor steps per JOG encoder click (Jog sensitivity)
// Higher value = faster film movement per click
#define JOG_STEPS_PER_CLICK 32

// U-shaped optical sensor debounce time (microseconds)
#define SENSOR_DEBOUNCE_US 15000 // 15ms

// Shutter trigger pulse duration (ms)
#define SHUTTER_PULSE_MS 300

// Post-shutter delay — wait for camera to finish exposure & save file (ms)
#define POST_SHUTTER_DELAY_MS 400

// Mechanical vibration settle time before triggering shutter (ms)
#define SETTLE_DELAY_MS 80

// Film advance timeout protection (ms)
#define FILM_TIMEOUT_MS 4500

#endif // CONFIG_H
